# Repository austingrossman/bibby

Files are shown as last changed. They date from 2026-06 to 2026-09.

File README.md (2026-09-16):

# bibby — Brew In A Bag Temperature Ramp Controller

`bibby` is a temperature and power controller for electric brew-in-a-bag (BIAB)
brewing, running on a Raspberry Pi 5. It reads kettle temperature from a PT100
RTD, drives two mains heating elements through solid-state relays (SSRs), and
presents a touch UI for setting and tracking the brew temperature. Power is
delivered as a duty cycle synchronized to the AC mains zero crossing, and the
whole system is built so that any fault, crash, or hang leaves the heaters
**off**.

This README is meant to let someone unfamiliar with the project understand it,
reproduce the hardware, build the software, and calibrate it for their own
kettle. It moves from the big picture down to the details: architecture, then
hardware, then software, then build/bring-up, then calibration.

This project is for fun. I am doing it to improve my home brewing set up. I hope
that someone sees inspiration in this project and does something similar. I am
doing this with a couple specific goals in mind:
- Learn to use AI for coding purposes.
- I recently purchased a Mac mini. I will only use a Mac for this project and it
  forces me to learn how to use it.
- I've recently acquired a 3D printer. This project has one 3D printed part, so
  I should learn how to use it.

---

## Table of contents

1. [System overview](#1-system-overview)
2. [Software architecture](#2-software-architecture)
3. [Safety design](#3-safety-design)
4. [Hardware](#4-hardware)
5. [Raspberry Pi bring-up and installation](#5-raspberry-pi-bring-up-and-installation)
6. [Building bibby](#6-building-bibby)
7. [Configuration](#7-configuration)
8. [Running](#8-running)
   - [Web interface — screen mirror + log browser](#web-interface)
9. [Calibration methodology](#9-calibration-methodology)
10. [Data logging](#10-data-logging)
11. [Repository layout](#11-repository-layout)
12. [License](#12-license)

---

## 1. System overview

The controller is a **single process** with three threads sharing one in-memory
state block of C11 atomics (the optional web interface adds a few more, none of
them on the control path — §2.9):

```
  +----------------------------------------------------------------+
  |                    bibby (one process)                          |
  |                                                                |
  |  main/UI thread          sampler thread         SSR thread     |
  |  ---------------         ------------------     -------------  |
  |  LVGL touch UI on        60 Hz, DRDY-paced:     SCHED_FIFO,    |
  |  /dev/fb0 (rotated)      - MAX31865 read        ZC-paced:      |
  |  - kettle readout        - temp filter          - zero-cross   |
  |  - charts, slider        - PID (watts)            capture      |
  |  - fault band            - power split          - sigma-delta  |
  |          |               - CSV logging            SSR firing   |
  |          |               - batch-size estimator - watchdogs    |
  |          v                     |                     |         |
  |  +------------------ BibbyState (C11 atomics) -------+         |
  |            duties, temps, modes, faults, history               |
  +----------------------------------------------------------------+
        | SPI0 + DRDY (GPIO16)      | GPIO20 ZC     | GPIO21/26
        v                           |               v
  +-------------+            +-------------+   +-----------+
  |  MAX31865   |            | zero-cross  |   |   SSR1    |
  |  + PT100    |            | detector    |   |   SSR2    |
  +-------------+            +-------------+   +-----------+
        ^                          ^                |
        | RTD                      | AC mains       | switched mains
     kettle probe                  line sense       to heating elements
```

- The **SSR thread** owns the relays. It runs at real-time priority
  (`SCHED_FIFO`) so a GUI stall can never delay the zero-cross response or the
  watchdogs.
- The **sampler thread** owns the sensor and the control law. It publishes
  per-element duty commands into the shared state; it never touches the relays.
- The **UI thread** is a pure view/controller: it renders the state and writes
  user intent (setpoint, mode, manual watts). Nothing in it is on the control
  or safety path.
- Optionally, the **web interface** (§2.9) adds an accept thread, a
  framebuffer-capture thread and a short-lived thread per HTTP connection. They
  run at normal priority, hold no control state of their own, and reach the
  controller only by injecting pointer events into the UI — so everything above
  is unchanged whether it is running or not.

### Why a duty cycle synchronized to zero crossing?

The heating elements are resistive loads switched by zero-cross SSRs. Switching
only at the AC zero crossing eliminates the inrush/EMI of phase-angle control.
Power is modulated by choosing *which* mains half-cycles to pass — a duty cycle
in `[0, 1]`. A sigma-delta modulator (§2.3) spreads the fired cycles out evenly
so the average power tracks the command with minimal low-frequency flicker.

### Why watts, not duty?

The control law works in **watts**: the PID outputs a total power demand, and a
splitter turns watts into per-element duties using the configured element
ratings. This makes the tuned gains independent of which elements are fitted —
swap elements, update `bibby.ini`, and the loop still commands the same power
per degree of error. It also enables the equal-flux split and anti-scorch cap
(§2.4), which need to know real watts per cm².

---

## 2. Software architecture

### 2.1 Shared state — `src/state.{h,c}`

`BibbyState` is a single struct of C11 atomics shared by the three threads —
no locks on the hot paths. Key fields:

| Field | Writer | Purpose |
|---|---|---|
| `duty1`, `duty2` | sampler | per-element duty commands in `[0,1]` |
| `p_demand_w` | sampler | commanded power — also the delivered average power (§2.3) |
| `temp_raw_c`, `temp_filt_c`, `temp_valid` | sampler | latest sensor sample and validity |
| `setpoint_c`, `manual_mode`, `manual_power_w`, `grain_in` | UI | user intent |
| `simulate_zc` | main, at startup | bench zero-cross simulation (`mains.simulate_zc` / `--sim-zc`); never changes while running |
| `output1`, `output2`, `zc_count`, `watchdog_alarm` | SSR thread | fired state, ZC counter, ZC watchdog |
| `control_heartbeat` | sampler | bumped every loop pass; the SSR thread's staleness watchdog watches it |
| `rtd_fault`, `rtd_unresponsive`, `fault_forced_manual` | sampler | sensor-fault state |
| `m_est_l`, `adaptive_scale` | sampler | batch-size estimate (litres) and gain scale |
| `running` | main | global shutdown flag |

A mutex-guarded ring buffer of `HistPoint`s (one per 0.5 s) feeds the UI
charts; it is the only locked structure, and only the UI and the sampler's
0.5 s slow tick touch it.

### 2.2 Sampler thread — `src/sampler_thread.c`

Paced by the MAX31865 DRDY edge (one conversion per mains cycle, so ~60 Hz):

1. **Wait** for a DRDY falling edge (500 ms timeout so a dead sensor cannot
   stall the loop — the read also checks the DRDY level directly, so a missed
   edge still yields the conversion).
2. **Read** the sensor (§2.5); fresh samples go through the temperature filter
   (§2.6) and into the shared state.
3. **Mode interlock:** any RTD fault, unresponsive sensor, or invalid
   temperature forces **manual mode at zero watts** — automatic control can
   never command power on bad data.
4. **Control law** (§2.4): manual watts pass straight through; in auto, the
   watts-based PID runs once per fresh sample.
5. **Power split** (§2.4) turns the demand into `duty1`/`duty2`.
6. **Slow tick (0.5 s):** publish the batch-size estimate (§2.7) and push a
   chart history point.
7. **CSV logging** (§10): one row per fresh sample (or per 0.5 s during an
   outage, so faults stay on disk).

### 2.3 SSR thread — `src/ssr_thread.c`, `src/sigma_delta.h`

Runs at `SCHED_FIFO` (real-time) priority, pinned to the AC zero crossing:

1. **Zero-cross capture.** Wait for a rising edge on GPIO20 (libgpiod v2 edge
   events) with a mains-derived timeout: half-period + 0.7 ms guard — 9.0 ms at
   60 Hz, 10.7 ms at 50 Hz.
2. **Sigma-delta modulation.** Each zero crossing, add each element's duty
   fraction to a per-channel accumulator; fire that SSR for the half-cycle when
   the accumulator reaches 1.0 and subtract 1.0. The accumulator is capped at
   2.0 to bound catch-up after forced-off stretches. This is a first-order
   delta-sigma DAC clocked by the mains: the average fired fraction equals the
   commanded duty with the switching energy pushed to high frequency.
3. **Zero-cross watchdog.** No edge within the timeout → both SSRs forced off,
   `watchdog_alarm` set. A lost mains-sense signal must not leave a relay
   latched on. `simulate_zc` substitutes the timeout tick for the edge so the
   modulator can be exercised with no mains connected. It is set once at
   startup from `mains.simulate_zc` (or `--sim-zc`) and there is deliberately
   **no control for it on the panel**: while it is on this watchdog can never
   trip, which is a commissioning decision, not something a stray tap during a
   brew should be able to do. Startup logs a warning line whenever it is on.
4. **Control-staleness watchdog.** The sampler bumps `control_heartbeat` every
   pass; if it stops advancing for ~2 s worth of zero crossings
   (`2 × mains_Hz`), duties are forced to zero — a wedged control loop must not
   leave the heaters running. (`BIBBY_TEST_WEDGE=<sec>` wedges the sampler once,
   5 s in, to demonstrate exactly this on the bench.)

### 2.4 Control law — `src/control.c`, `src/power_split.c`

**PID (watts).** `p = kp·e`, integrator accumulates raw per-sample error
(`ki` is W/°C per sample), derivative is a raw per-sample delta. Output is
`clamp(ff + p + i + d, 0, max_power)` in watts. Anti-windup is **conditional
integration**: the integrator holds whenever the non-integral output is already
against a rail and the error would push further into it; a backstop clamps the
integral term to full output authority (`max_power / ki`).

**Integral clamp** (`pid.i_clamp_w`, watts; 0 = off). On top of that, the
integral *term* is bounded to ±`i_clamp_w` — the accumulator itself is held to
`i_clamp_w / ki`, every step, whether or not the integrator was allowed to
move. It is a statement of how much authority the integrator may ever have:
with the feedforward carrying the holding power, all the integrator has to
trim is model error, so it never needs kilowatts. The shipped value is 500 W,
about 5 % of the installed 10.5 kW — enough to absorb a wrong ambient or a
drifting `k_loss`, far too little to run away with the kettle. The tighter of
this and the `max_power / ki` backstop wins, and it applies to both gain sets.

**Integral separation** (`pid.i_band_c`, °C; 0 = off). The integrator only
accumulates while `|error| ≤ i_band_c`; outside the band it holds its value,
neither growing nor resetting. Anti-windup alone is not enough on this plant:
the kettle is an integrator, so a PI with an accurate feedforward must finish
a setpoint change with its integrator back near zero, which means every
degree-second of error it soaked up during the approach is paid back as
overshoot after the crossing. In the 2026-09-07 ramp test that accounted for
the whole 0.73 °C overshoot on a 10 °C step: the output was railed (and the
integrator held) only for the first 4 °C, then the integrator wound up for
250 s across the unsaturated approach and was still commanding 1.7 kW over
the holding power when the temperature first touched setpoint. With the
feedforward carrying the holding power the integrator has only model error to
trim, and there is nothing useful for it to learn while the temperature is
still degrees away, so the band confines it to the last half degree. The
band applies to both gain sets.

**Holding feedforward.** `ff = (setpoint − ambient_c) / process_gain_c` watts,
clamped to `[0, max_power]` — the steady-state power needed to hold the
setpoint, supplied directly so the integrator only trims model error (§9.6).
Zero gain disables it.

**Grain-in gain set.** The "Grain In" toggle swaps in an alternate gain set
(`grain.kp/ki/kd`) and optionally caps power (`grain.max_power_w`) — the plant
changes when grain is added, and scorch risk rises. Zero grain gains mean
"same as main gains disabled" (auto commands no power in grain mode until they
are set).

**Adaptive gain scaling** (config-gated, off by default). The batch-size
estimate in litres (§2.7) divided by `adaptive.m_ref_l` scales `kp`/`kd`
within `[scale_min, scale_max]` — a half-size batch gets half the gain without
retuning.

**Equal-flux power split.** Demand is split so both elements run at the same
surface power density (W/cm²): proportional to area, with saturation overflow
pushed to the other element and everything clamped to the element ratings.
With different elements (e.g. 5000 W/820 cm² + 5500 W/473 cm²) the duties are
deliberately unequal — same flux, different power. `power.max_flux_w_cm2`
optionally caps total demand at `flux × total_area` (anti-scorch; 0 disables).

### 2.5 MAX31865 RTD sensor — `src/max31865.c`

- PT100, **3-wire**, 400 Ω nominal reference resistor, on `/dev/spidev0.0` at
  1 MHz, `SPI_MODE_1`.
- **Init sequence:** set 3-wire + clear faults + mains filter notch → enable
  VBIAS (10 ms settle) → enable auto-conversion (20 ms) → discard the first 10
  conversions using DRDY polling (they settle after VBIAS/auto enable).
- **Mains filter:** config-register bit 0 selects the noise-rejection notch
  (set = 50 Hz, clear = 60 Hz). It is set from `mains.frequency_hz` (§7) in the
  first config word — before auto-conversion, as the datasheet requires.
- **`max31865_read()` is non-blocking:** it checks the DRDY level (GPIO16,
  active-low); not ready → previous value with `fresh=false`. Otherwise it
  burst-reads RTD + fault registers in one SPI transaction, converts via
  Callendar–Van Dusen, and applies the per-unit `Rref`/gain/offset calibration
  (§9.1–9.2).
- **Fault handling:** the RTD-LSB fault bit and Fault Status register are
  checked every read. A faulted conversion is rejected (the stale value is held
  so the filter is not poisoned) and the latch cleared so the status reflects
  the next conversion. `max31865_fault_text()` decodes the register for the UI
  fault band.

The MAX31865 datasheet is included at [`docs/MAX31865.pdf`](docs/MAX31865.pdf).

### 2.6 Temperature filter — `src/temp_filter.c`

Cascaded boxcar (moving-average) stages — order and window from `bibby.ini`
(default 2 × 40 samples ≈ a second-order CIC with triangular weighting, ~0.65 s
group delay at 60 Hz). The first sample primes every stage so the output starts
at the true temperature instead of ramping from zero.

### 2.7 Batch-size estimator — `src/mass_estimator.c`

During any stretch of roughly constant commanded power (taken as 0 W while the
ZC watchdog holds the SSRs off) where the temperature rises ≥ 1 °C, the kettle behaves as an integrator: `dT/dt = P/(m·c)`. A
least-squares slope over the stretch gives the thermal mass `P/slope` in J/°C,
which is reported as the equivalent litres of water, `m = (P/slope)/4186`, so
the number on the status line (`m 53.2 L`) and in the log (`m_est_l`) is a
batch size a brewer can sanity-check against what they poured in. It reads a
little high because the kettle, elements and hoses count as water, and it
reads `1/s` high when the elements put out a fraction `s` of their rated watts
(the shipped setup reads 53 L for 45 L poured; §9.4). It is always computed
and logged; feeding it back into the gains is the separate, config-gated
adaptive scaling of §2.4.

### 2.8 UI — `src/ui/`

LVGL 9.3 rendering directly to the framebuffer:

- **Display:** `lv_linux_fbdev` on `/dev/fb0`; the physical panel is portrait,
  mounted sideways, so the UI renders 1280×720 and LVGL software-rotates 90°
  into the 720×1280 framebuffer (`ui.rotation`). Touch comes from the first
  evdev device advertising absolute multitouch (`ui.touch_device = auto`).
- **Layout:** two large square toggles (Grain In, Manual Control) and the
  ±10/±1/±0.1 setpoint steppers on top; temperature chart (setpoint, filtered,
  raw, grain and mode-change markers) and power/PID-term chart below, each
  between a row of tappable legend chips above and a time scale below; a wide
  vertical power slider (manual watts in manual, live demand readout in auto);
  kettle graphic whose element glow follows the commanded duties and whose
  contents carry the batch-size estimate in litres and gallons, with the
  per-element duties and the adaptive gain scale under it; fault band (decoded
  RTD faults, watchdog, forced-manual notice).
- **Time scale:** both charts are right-aligned to *now* and span
  `ui.chart_window_min`, so the scale is fixed at startup and drawn once —
  six marks running `-5m … -1m … now` for the default 5-minute window, landing
  exactly on the chart's vertical grid lines (sub-minute marks read `-0:30`).
- **No dead space.** The two panes stretch from just under the toggles to the
  bottom edge. The fault band has no reserved strip: it is hidden nearly
  always, so it floats over the lower third of the power chart when it
  appears, which costs nothing — the loop is at zero watts by then.
- **Sized for fingers, not a mouse.** Every target is a touch target: the two
  toggles are 180×160, the steppers 120×75, the legend chips 46 px tall, and
  the power slider is 104 px wide — it is the only continuous control on the
  screen, so it gets a thumb's worth of track. The one thing the panel
  deliberately cannot do is arm zero-cross simulation (§2.3).
- LVGL is pinned to **v9.3.0**: v9.4 breaks the fbdev software-rotation path
  and hangs in `lv_deinit` on shutdown.
- **Memory (`src/ui/lv_conf.h`):** LVGL's built-in allocator is a fixed pool
  sized for microcontrollers — 64 KB by default, and this screen sits at ~36 KB
  of it with peaks near 42 KB, so a large redraw could exhaust the remainder and
  assert inside `lv_draw_add_task` ("Out of memory"). bibby therefore sets
  `LV_USE_STDLIB_MALLOC = LV_STDLIB_CLIB`: LVGL allocates from the system heap
  and there is no ceiling to tune.
- **Assertions:** LVGL's default `LV_ASSERT_HANDLER` is `while(1);`, which would
  wedge the UI thread at 100 % CPU — panel frozen, SIGTERM ignored, control
  threads still driving the elements. bibby sets it to `abort()` instead: the
  process dies, the kernel drops the GPIO requests, the SoC pull-downs hold the
  SSR inputs low, and `bibby.service` restarts it (§5.3).
- The kernel console shares `/dev/fb0` and will draw its blinking cursor over
  the UI; the systemd unit unbinds it (§5.3).

`bibby --ui-test` shows a bring-up screen instead: border, corner labels, and a
crosshair that follows the finger — verifies rotation and touch mapping before
trusting the real UI.

### 2.9 Web interface — `src/web/`

Optional, off by default, and configured entirely from `[web]` in `bibby.ini`
(§7). When enabled it adds an HTTP server on the LAN with two screens: a live
mirror of the touchscreen that can be tapped from a phone or laptop, and a
browser for the CSV run logs. Operator's guide in §8; safety in §3.

```
             browser                       bibby process
   ┌──────────────────────────┐   ┌────────────────────────────────────┐
   │  Screen tab              │   │  accept thread ─┬─ conn thread ─┐  │
   │   <img> long-poll   ─────┼───┼──> /api/screen.png              │  │
   │   pointer events    ─────┼───┼──> /api/input                   │  │
   │                          │   │                                 v  │
   │  Logs tab                │   │        capture thread     pointer  │
   │   file list, charts ─────┼───┼──> /api/logs /api/log     queue    │
   │   CSV download      ─────┼───┼──> /api/log/download        │      │
   └──────────────────────────┘   │             │               │      │
                                  │        mmap /dev/fb0        │      │
                                  │             │          UI thread   │
                                  │             └──────────> LVGL indev│
                                  └────────────────────────────────────┘
```

- **Screen mirror.** The capture thread `mmap`s `/dev/fb0` read-only and
  compares it against the previous frame; only a genuine pixel change bumps the
  frame sequence. It captures at most `web.screen_fps` times a second, and only
  while a browser is actually asking — an unwatched panel costs nothing.
  Requests **long-poll**: the server holds `/api/screen.png?seq=N` until the
  screen differs from the client's frame `N` (or 10 s pass, answering `204`), so
  a static screen uses no bandwidth and a touch appears within one frame.
  Frames are encoded as PNG (zlib, "Up" filter) — about 50 KB for a full
  1280×720 frame, and `?scale=2` halves each dimension for slow links.
- **Un-rotation.** The framebuffer is the *physical* portrait panel, sideways;
  the mirror applies `ui.rotation` so the browser shows what the operator at the
  kettle sees. The forward map is the same one LVGL uses on pointer input, so
  "display space" here is exactly LVGL's logical screen.
- **Pointer injection.** Taps post to `/api/input` in display coordinates. The
  server maps them back to panel coordinates and pushes them onto a small queue;
  a **second LVGL pointer indev**, created on the UI thread, drains that queue
  and reports the samples exactly as the evdev touchscreen does — so LVGL
  applies the same rotation to a remote tap as to a finger, and it lands on the
  pixel it looks like it lands on. LVGL is single-threaded and this queue is the
  entire boundary: no web thread ever makes an `lv_*` call. A press with no
  follow-up is auto-released after 2 s, so a browser that vanishes mid-drag
  cannot leave a widget held down.
- **Log browser.** `/api/logs` walks the CSV tree; `/api/log` streams one file
  through a bounded-memory decimator (rows accumulate into buckets; when the
  bucket array fills, adjacent buckets merge pairwise and the rows-per-bucket
  doubles) and returns a whole-file average of at most ~1400 points per series.
  A 75 MB, 459 k-row tuning log becomes 136 KB of JSON in about a second.
  `/api/log/download` serves the raw CSV, including the run in progress.
- **Path safety.** Every client-supplied path is `realpath()`d and required to
  resolve inside `~/bibby/logs` and to be a regular `.csv` file, so the server
  cannot be talked into serving anything else.
- **Authentication.** HTTP Basic against `web.user` / `web.password`, compared
  length-independently so a wrong password cannot be narrowed down by timing.
  The server **refuses to start with an empty password**. Failures are logged
  and answered after a 300 ms delay.
- **Cost.** Nothing at all when no browser is watching — the capture thread
  sleeps on a condition variable. With one browser on the Screen tab, measured
  on a Pi 5 at 1280×720 (percentages are of **one** core, of four; bibby idles
  at ~1.4 %):

  | | per frame | 2 fps | 5 fps |
  |---|---|---|---|
  | full resolution | ~19 ms, ~48 KB | ~5 % | ~11 % |
  | `scale=2` | ~8 ms, ~25 KB | ~3 % | ~6 % |

  The cost is linear in `web.screen_fps`, and the dominant term is the
  **un-rotate/pixel conversion (~8 ms), not the PNG compression (~11 ms
  including the filter)** — rotating means walking the framebuffer down a
  column, which defeats the cache. Two things keep it in hand: the conversion
  precomputes a per-pixel and per-row byte step instead of transforming each
  pixel's coordinates (worth ~10×), and the build is optimized (§6 — an
  unoptimized build costs ~67 ms per frame instead of 19). The web threads run
  at normal priority and are not on the control path; the SSR thread's
  `SCHED_FIFO` and the staleness watchdog are unaffected either way.
- The page is a single self-contained HTML file (`src/web/www/index.html`, no
  external assets or CDN) compiled into the binary at build time, so an
  installed `bibby` has no companion asset directory to lose.

---

## 3. Safety design

This system switches mains voltage into multi-kilowatt heating elements, so the
**default state is always off**. The design requirements and how they are met:

| Requirement | Mechanism |
|---|---|
| Heaters off at startup | SSR GPIO lines are requested with output value low before any thread runs |
| Heaters off on exit/crash | the kernel releases the GPIO lines when the process dies — for any reason — and the SoC pull-downs hold the SSR inputs low; SIGINT/SIGTERM additionally shut down in order |
| Only one instance | `flock` single-instance guard (`src/single_instance.h`); the kernel drops the lock on any exit |
| Heaters off if mains-sense (ZC) is lost | mains-derived zero-cross watchdog (~9 ms at 60 Hz) forces SSRs off, raises `watchdog_alarm`. The one thing that defeats it is bench mode (`mains.simulate_zc`, §2.3), which is why it lives in the config file and has no control on the panel |
| Heaters off if the control loop wedges | control-staleness watchdog: sampler heartbeat stalled for ~2 s of ZCs → duties forced to zero |
| GUI stalls cannot delay safety logic | the SSR thread runs `SCHED_FIFO`; the UI is not on the control path |
| No power commanded on unreliable temperature | RTD fault / unresponsive sensor forces manual mode at zero watts; auto is unreachable until the sensor is healthy |
| Power commands always bounded | demand clamped to the configured element ratings (and the optional flux cap) before splitting; duties clamped to `[0,1]` |
| The integrator cannot run away | conditional-integration anti-windup, plus a hard ± bound on the integral term (`pid.i_clamp_w`, 500 W as shipped) and the `max_power / ki` backstop (§2.4) |
| A vanished web client cannot hold a control down | an injected press with no follow-up sample is released after 2 s |
| Controller returns after a crash | `Restart=always` in the systemd unit (§5.3); SSRs are safe during the gap per the kernel-release mechanism above |
| Remote control cannot bypass an interlock | the web interface owns no control logic: it injects pointer events into the same LVGL widgets a finger drives (§2.9), so mode interlocks, clamps and watchdogs apply identically |
| Remote control is off unless deliberately enabled | `[web]` is disabled by default and the server refuses to start without a password; `web.allow_control = false` serves a read-only mirror |

---

## 4. Hardware

### 4.1 Major components

| Item | Notes |
|---|---|
| Raspberry Pi 5 | GPIO chip is `/dev/gpiochip4` on Pi 5 |
| Touchscreen display | 720×1280 DSI panel (Goodix touch), mounted sideways; UI software-rotates 90° |
| PT100 RTD probe | 3-wire, immersed in the kettle |
| 2 × zero-cross SSR | One per heating element; switched by GPIO21 / GPIO26 |
| 2 × resistive heating element | Mains-powered, BIAB kettle (this build: 5000 W and 5500 W) |
| Custom Pi HAT PCB | Sensor front-end + zero-cross detector (§4.2) |

> **TODO (fill in your build):** exact display model, SSR part numbers and
> current rating, fusing/contactor, and mains connector. These are
> deployment-specific and not captured in the repo.

### 4.2 Raspberry Pi HAT PCB — `pi_hat/bibby_pi_hat/`

A KiCad 7+ project (`.kicad_sch`, `.kicad_pcb`, `.kicad_pro`). Open it in KiCad
to view/edit the schematic and board, or to regenerate gerbers
(`pi_hat/bibby_pi_hat/gerbers/`). The HAT carries two functional blocks:

**RTD front-end (U1 — MAX31865):**
- `R1` = 400 Ω 0.1 % — RTD reference resistor (`Rref`). Precision and tempco here
  set the measurement accuracy; this is one of the two per-unit calibration
  anchors (§9.1).
- `C1`, `C3` = 0.1 µF — decoupling / RC filtering.
- SSOP-20 package; SPI to the Pi plus the DRDY data-ready line.

**AC zero-cross detector (U2 — H11AA1 AC-input optocoupler):**
- The H11AA1 has an anti-parallel LED input, so it conducts on both mains
  half-cycles and its phototransistor output pulses around each zero crossing.
- `R3`–`R6` = 43 kΩ, `R2` = 20 kΩ, `R7` = 1 MΩ (! DNI !) — line current-limiting
  and pull/bias network for the optocoupler. The pulse train feeds GPIO20.
- Solder jumpers `JP1`/`JP2`/`JP3` select options on the board.

**Connectors:**
- `J1` — 2×20 stacking header to the Pi GPIO.
- `J2` — Phoenix 1×10 5.08 mm terminal block (field wiring: RTD, mains sense,
  SSR drive).

> The complete, authoritative bill of materials and net list is the KiCad
> schematic itself. The values above are transcribed from it for orientation.

### 4.3 Pin assignments (40-pin header)

| Pin | GPIO | Signal | Direction | Used by |
|---|---|---|---|---|
| 1 | — | 3.3 V | Power | MAX31865 VIN |
| 6 | — | GND | Power | MAX31865 GND |
| 19 | GPIO10 | SPI0 MOSI | Out | MAX31865 SDI |
| 21 | GPIO9 | SPI0 MISO | In | MAX31865 SDO |
| 23 | GPIO11 | SPI0 SCLK | Out | MAX31865 CLK |
| 24 | GPIO8 | SPI0 CE0 | Out | MAX31865 CS |
| 36 | GPIO16 | DRDY | In | MAX31865 DRDY (sampler thread) |
| 37 | GPIO26 | SSR2 | Out | SSR thread |
| 38 | GPIO20 | Zero Cross | In | SSR thread |
| 40 | GPIO21 | SSR1 | Out | SSR thread |

### 4.4 Electrical / wiring overview

```
   MAINS L ---+----------------------------+--------------------+
              |                            |                    |
              |                       [SSR1 load]          [SSR2 load]
              |                            |                    |
        [ZC detector U2]             [Element 1]          [Element 2]
              |  (opto, isolated)          |                    |
              v                       [SSR1 line]          [SSR2 line]
        GPIO20 (ZC in)                     ^                    ^
                                           |                    |
   Pi 3.3V/GPIO control side:        GPIO21 (SSR1)        GPIO26 (SSR2)
                                      drive (3.3V logic into SSR input)

   PT100 RTD --3 wires--> MAX31865 (U1) --SPI0 + DRDY--> Pi
```

- The H11AA1 provides **galvanic isolation** between the mains line-sense and
  the Pi logic.
- The SSRs are driven by 3.3 V GPIO on their input side; their output side
  switches mains into the elements.
- The RTD is a low-voltage measurement isolated from the mains by the kettle
  and the sensor front-end.

> **WARNING:** mains wiring, fusing, grounding/earth bonding, and enclosure
> safety are the integrator's responsibility. Use appropriately rated SSRs and
> heat-sinking, a proper earth connection to the kettle, and a
> contactor/fuse/breaker sized to the elements.

### 4.5 Enclosure

> **TODO (fill in your build):** enclosure material and dimensions, panel cutout
> for the display, ventilation/heat-sinking for the SSRs, and how the Pi + HAT +
> SSRs are mounted. Add photos and mechanical drawings here.

---

## 5. Raspberry Pi bring-up and installation

Tested target: **Raspberry Pi 5**, 64-bit Raspberry Pi OS.

### 5.1 OS and interfaces

1. Flash Raspberry Pi OS (64-bit) and boot the Pi. Install a beefy SD card (or
   other storage) for logging. Find a way to remote-login to the Pi.
2. Enable SPI:
   ```
   sudo raspi-config   # Interface Options -> SPI -> Enable
   ```
   Confirm `/dev/spidev0.0` exists after reboot.
3. The DSI touch display is auto-detected (`display_auto_detect=1` in
   `/boot/firmware/config.txt`). The touch controller registers as a Goodix
   evdev device; bibby finds it automatically.
4. The Pi 5 exposes GPIO via `/dev/gpiochip4`; the code opens it directly. The
   user running bibby needs the `gpio`, `spi`, `video`, and `input` groups (or
   run via the systemd unit, §5.3).

### 5.2 Build dependencies

```
sudo apt update
sudo apt install -y build-essential cmake git libgpiod-dev zlib1g-dev
```

- **libgpiod v2** is required (the code uses the v2 edge-event API). Confirm
  with `gpiodetect` / `pkg-config --modversion libgpiod`.
- **LVGL** is fetched and built from source by CMake (FetchContent) — nothing
  to install. It renders straight to the framebuffer; no X, Wayland, or GL
  stack is needed.
- The analysis tools (§9.4) additionally want
  `pip3 install numpy scipy matplotlib pandas` on whatever machine runs them.

### 5.3 Autostart at boot (systemd)

[`deploy/bibby.service`](deploy/bibby.service) is the reference unit. Besides
starting bibby it handles three things the app cannot do for itself:

- **Unbinds the kernel console from the framebuffer** (`vtcon1`) before start —
  otherwise the console's blinking cursor (and any kernel message) draws over
  the UI — and rebinds it on stop.
- **`LimitMEMLOCK=64M`** so `mlockall(MCL_CURRENT)` succeeds (the default 8 MB
  is too small once LVGL is linked in).
- **`AmbientCapabilities=CAP_SYS_NICE`** so the SSR thread gets its `SCHED_FIFO`
  real-time priority without running the whole process as root.

Install:

```
sudo cp deploy/bibby.service /etc/systemd/system/
sudo systemctl daemon-reload
sudo systemctl enable --now bibby
```

Check status and logs with `systemctl status bibby` / `journalctl -u bibby -f`.
Adjust `User=` and the paths in the unit for your username/checkout. The unit
uses `Restart=always`: the controller comes back if it ever dies, and the SSRs
are safe during the gap (§3).

---

## 6. Building bibby

```
git clone <repo-url> bibby
cd bibby
cmake -S . -B build -DCMAKE_BUILD_TYPE=Release
cmake --build build -j
```

If you omit `CMAKE_BUILD_TYPE`, CMake would normally configure with **no `-O`
flag at all**; `CMakeLists.txt` therefore defaults it to `RelWithDebInfo`
(`-O2 -g`) when it is unset. This matters more than it sounds: an unoptimized
build runs LVGL's renderer and the web mirror's pixel conversion roughly four
times slower (§2.9). Check an existing build tree with

```
grep C_FLAGS build/CMakeFiles/bibby.dir/flags.make
```

and re-run `cmake -S . -B build -DCMAKE_BUILD_TYPE=RelWithDebInfo` if it shows
no `-O2` — a build directory keeps whatever type it was first configured with.

The first configure fetches LVGL (pinned to v9.3.0 — see §2.8) from GitHub.
Two binaries result:

- `build/bibby` — the controller (links `lvgl`, `gpiod`, `z`, `m`, `pthread`,
  `rt`; `z` is only used by the web screen mirror, §2.9)
- `build/tests` — unit tests for the pure modules (no hardware needed):

```
./build/tests
```

`build/` and `logs/` are gitignored. There is no install step yet; run from the
build tree (the systemd unit does the same). The config file is found relative
to the executable (§7), so a copied-out binary works if `bibby.ini` sits next
to it.

---

## 7. Configuration

Runtime parameters that depend on the install (mains region, heating elements,
control gains, calibration) live in **`bibby.ini`**, **not** in the source.
There is no reason to edit a constant in code and rebuild to adapt a new brew
setup.

**Lookup order:** `-c <path>` argument → `$BIBBY_CONFIG` environment variable →
`bibby.ini` next to the executable → `bibby.ini` in the current directory.
A missing file or unknown key falls back to a built-in safe default (60 Hz,
zero gains), so the system still comes up. Comments (`#` or `;`, inline
allowed) and blank lines are ignored.

All keys, with their defaults:

| Key | Default | Effect |
|---|---|---|
| `mains.frequency_hz` | 60 | ZC watchdog timeout (half-period + 0.7 ms), staleness cutoff (2×Hz ZCs ≈ 2 s), MAX31865 notch (50/60 Hz) |
| `mains.simulate_zc` | false | **bench only:** treat ZC-watchdog timeouts as zero crossings, so the whole loop runs with no AC connected (§2.3). The mains-loss watchdog cannot trip while it is on, so it is a config switch with no panel control; `--sim-zc` forces it on for one run |
| `element1.watts` / `element2.watts` | 2500 / 2500 | element ratings; their sum is the maximum power demand |
| `element1.area_cm2` / `element2.area_cm2` | 150 / 150 | wetted areas driving the equal-flux split |
| `power.max_flux_w_cm2` | 0 (off) | anti-scorch cap: total demand ≤ flux × total area |
| `pid.kp` / `ki` / `kd` | 0 | watts-based gains (§9.5); zero = auto commands no power |
| `pid.i_band_c` | 0 (off) | integral-separation band, °C: the integrator only accumulates within it (§2.4); both gain sets |
| `pid.i_clamp_w` | 0 (off) | ± bound on the integral term, watts (§2.4); the tighter of this and the `max_power / ki` backstop applies; both gain sets |
| `grain.kp` / `ki` / `kd` | 0 | alternate gain set while "Grain In" is on |
| `grain.max_power_w` | 0 (off) | power cap while grain is in |
| `feedforward.process_gain_c` | 0 (off) | identified K [°C/W]; holding feedforward `(setpoint−ambient)/K` watts |
| `feedforward.ambient_c` | 20 | feedforward reference temperature |
| `sensor.ref_resistor_ohms` | 400 | MAX31865 Rref, ice-point trimmed (§9.1) |
| `sensor.temp_cal_gain` / `temp_cal_offset` | 1.0 / 0.0 | two-point span trim, `T_true = g·T + b` (§9.2) |
| `filter.order` / `filter.window` | 2 / 40 | boxcar cascade stages and window length (§2.6) |
| `logging.rate` | high | `high` = row per sample (60 Hz); `low` = row per `low_period_s` |
| `logging.low_period_s` | 2.0 | row period in low-rate mode |
| `ui.chart_window_min` | 5 | chart time window, minutes (1–30) |
| `ui.rotation` | 90 | UI rotation onto the panel: 0/90/180/270 |
| `ui.fb_device` / `ui.touch_device` | auto | `auto` = `/dev/fb0` / first multitouch evdev; or explicit paths |
| `web.enable` | false | start the web interface (§8); ignored unless `web.password` is set |
| `web.port` | 8080 | TCP port |
| `web.bind` | 0.0.0.0 | `0.0.0.0` = whole LAN; `127.0.0.1` = the Pi only (ssh tunnel) |
| `web.user` / `web.password` | brewer / *(empty)* | HTTP Basic credentials; **empty password = server refuses to start**. No `#` or `;` (INI comment characters) |
| `web.allow_control` | true | `false` serves a read-only mirror — the screen updates, taps are rejected |
| `web.screen_fps` | 5 | cap on mirror capture rate, 1–30 (only captures while a browser is watching) |
| `adaptive.enable` | false | scale kp/kd by (batch-size estimate / `m_ref_l`) |
| `adaptive.m_ref_l` | 0 | batch size the gains were tuned at, litres, as the estimator reads it (§9.5) |
| `adaptive.scale_min` / `scale_max` | 0.5 / 4.0 | clamp on the adaptive scale |

The shipped `bibby.ini` documents each value's derivation inline; §9 gives the
full procedures.

---

## 8. Running

```
./build/bibby                  # the normal touch UI
./build/bibby --ui-test        # display/touch bring-up screen (§2.8)
./build/bibby --headless       # no display: prints a status line every 2 s
./build/bibby --sim-zc         # start with simulated zero crossings (bench)
./build/bibby --manual-w 8000  # start in manual at 8000 W (plant-ID tests)
./build/bibby -c /path/to.ini  # explicit config
```

If the framebuffer cannot be opened the UI falls back to headless mode rather
than exiting — the controller and safety logic keep running.

### UI elements

- **Kettle card:** setpoint in °C and °F above it, the measured temperature in
  °C and °F at the same size inside it (°F a shade darker, so °C still reads
  first), the batch-size estimate on the contents in **litres and US gallons**,
  animated elements whose glow tracks the commanded duty, and a per-element
  duty readout below (`E1 x%  E2 y%` — these differ by design; see the
  equal-flux split, §2.4).
- **POWER slider:** commands watts in manual mode; shows the loop's live demand
  in auto (disabled for input). Total watts read out under it. It is 104 px
  wide — deliberately, for a wet thumb.
- **Setpoint steppers:** ±10 / ±1 / ±0.1 °C.
- **Toggles:** two square pads — Grain In (gain set swap + logged event marker)
  and Manual Control (manual watts vs PID auto). Zero-cross simulation is not
  among them; it is `mains.simulate_zc` in the config (§2.3, §7).
- **Charts:** temperature (setpoint / temp / raw + grain-event and mode-event
  markers — short dashes along the top edge at the samples where Grain In or
  Manual flipped) and power (demand W / ff / P / I / D), window set
  by `ui.chart_window_min`, y-autoscaled. Each carries a time scale under it
  reading backwards from `now` to the full window.
- **Chart legends:** each trace has a chip under its chart — tap to drop that
  trace. A hidden trace is neither drawn nor counted in that chart's autoscale,
  so switching off the terms you are not tuning zooms the pane onto the rest.
  Chips are colored when on, greyed and struck through when off; all traces
  start visible on every launch.
- **Fault band:** decoded RTD faults, watchdog alarm, and "Auto disabled →
  manual" when a fault forced the mode switch.
- **Status line:** the adaptive gain scale, under the per-element duties at the
  foot of the kettle column. (The batch-size estimate that drives it is on the
  kettle contents.)

### Web interface

Off by default. To turn it on, set a password in `[web]` (§7) and restart:

```ini
[web]
enable        = true
port          = 8080
bind          = 0.0.0.0        ; 127.0.0.1 to reach it only through an ssh tunnel
user          = brewer
password      = pick-something-long
allow_control = true           ; false for a read-only mirror
screen_fps    = 5              ; halve it if you want the CPU back; 2 is still responsive
```

Then browse to `http://<pi-address>:8080/` and enter the user and password.
Startup logs the URL it is serving and whether control is enabled:

```
web: mirroring /dev/fb0, panel 720x1280 32 bpp, rotation 90 -> 1280x720
web: http://0.0.0.0:8080/ as user "brewer" (remote control ENABLED)
web: remote pointer attached
```

**Screen tab** — a live mirror of the panel, upright the way you see it at the
kettle. It is the real framebuffer, not a re-drawing, so it shows exactly what
the touchscreen shows. Click or drag anywhere on it and the tap is injected
into the UI as a pointer event: setpoint steppers, the power slider, and the
toggles all behave as they do under a finger. Quality can be dropped to half
resolution for a weak connection. The mirror pauses while the Logs tab is open
or the browser tab is hidden.

**Logs tab** — every run under `~/bibby/logs` newest first (the run in progress
is marked "● live"). Pick one to plot it: temperature (filtered / raw /
setpoint) and power (demand, ff/P/I/D, and per-element duty on a
right-hand axis). Legend chips toggle traces, and hovering reads out every
visible series at that instant. **Download CSV** fetches the raw file — the
same one `tools/identify_plant.py` and `tools/plot_logs.py` expect — so a brew
can be pulled off the Pi from a laptop without ssh. Long logs are averaged
server-side to about 1400 points for plotting; the download is always the full,
unmodified file.

**Before you enable it, read this.** The mirror puts the kettle controls on
your network. Everything the panel can do, a browser with the password can do,
including raising the setpoint or commanding power on a multi-kilowatt element.
Every interlock still applies — remote taps go through the same widgets, so a
sensor fault still forces manual at 0 W, and the watchdogs are untouched — but
the *authorization* is only that password, over plain HTTP:

- Use it on a trusted home network, with a password you use nowhere else.
- **Do not forward the port through your router.** There is no TLS; anyone who
  can watch the traffic can read the password. For access from outside the
  house, set `bind = 127.0.0.1` and reach it through an ssh tunnel:
  `ssh -L 8080:localhost:8080 ramp` , then browse to `localhost:8080`.
- Set `allow_control = false` when you only want to watch a brew — the screen
  still updates live, but taps are rejected by the server.
- Leave `enable = false` if you do not want any of this; there is no default
  password and the server will not start without one.

**Bench testing without mains:** set `simulate_zc = true` in `[mains]`, or
start with `--sim-zc` to avoid editing the file. The SSR thread then clocks the
sigma-delta from its timeout tick instead of the missing zero-cross edge; the
full UI, control law, and logging run with no AC connected. Startup prints

```
bibby: ZERO-CROSS SIMULATION ON (--sim-zc) - the mains-loss watchdog cannot trip; bench use only
```

**Turn it off before the controller is wired to a kettle.** With it on, losing
the mains-sense signal looks exactly like normal operation to the SSR thread,
so the ZC watchdog — one of the interlocks in §3 — is inert. There
is no toggle for it on the panel for that reason: it should change when the
unit is on a bench, not when someone is brewing on it.

---

## 9. Calibration methodology

Three of the measurement constants are **per-unit** — they depend on the
specific RTD probe and the board's reference resistor, so they **must be
re-derived for any other board or probe**. All three live in the `[sensor]`
section of `bibby.ini`; **none require a code change or rebuild**. Their
identity defaults (`Rref` = 400 Ω, gain = 1.0, offset = 0.0) give a working but
uncalibrated sensor.

`tools/calibrate_sensor.py` does the §9.1/§9.2 arithmetic for you (standard
library only):

```
python3 tools/calibrate_sensor.py rref --ice-reading 1.4 --rref-current 400
python3 tools/calibrate_sensor.py span --p1 0.0 0.0 --p2 25.0 23.78
```

| `bibby.ini` key | Symbol | What it corrects |
|---|---|---|
| `sensor.ref_resistor_ohms` | `Rref` | one-point offset at the ice point (§9.1) |
| `sensor.temp_cal_gain` | `g` | span/slope error across temperature (§9.2) |
| `sensor.temp_cal_offset` | `b` | residual offset after the span fit (§9.2) |

The driver applies them in this order, so **calibrate in this order too**:

```
R_rtd  = (raw / 32768) * Rref            # ref_resistor_ohms  (§9.1)
T_cvd  = CVD(R_rtd)                      # Callendar–Van Dusen, fixed
T_true = g * T_cvd + b                   # gain, offset       (§9.2)
```

### 9.1 Reference resistor `Rref` (ice-point one-point trim)

`Rref` scales the entire resistance reading, so trimming it nulls a constant
offset. Trim it first, at a single known low temperature (the ice point is the
cheapest 0 °C reference available).

**Procedure**

1. Set `sensor.temp_cal_gain = 1.0`, `sensor.temp_cal_offset = 0.0` (so the
   span trim does not mask the reading), and `sensor.ref_resistor_ohms` to the
   board's nominal reference (400 Ω here — the value of `R1` on the HAT, §4.2).
2. Submerge the probe in a well-stirred ice-water bath and let it settle.
3. Read the measured temperature `T_ice` (the **raw** column in the CSV log,
   §10, before any span trim).
4. The PT100 resistance the probe *should* present at `T_ice` is, from
   Callendar–Van Dusen with `R0 = 100 Ω`, `A = 3.9083e-3`:
   `R_pt100(T) = 100·(1 + A·T + B·T²)`, which near 0 °C is ≈ `100·(1 + A·T)`.
   Because the reading scales linearly with `Rref`, the trimmed value is:

   ```
   Rref = Rref_nominal · 100.0 / R_pt100(T_ice)
   ```

**Worked example (this unit):** read **+1.4 °C** in the ice bath.
`R_pt100(1.4) = 100·(1 + 3.9083e-3·1.4) ≈ 100.547 Ω`, so
`Rref = 400 · 100.0 / 100.547 = 397.82 Ω` → `sensor.ref_resistor_ohms = 397.82`.

### 9.2 Span trim `gain`/`offset` (two-point line fit)

With `Rref` set, a probe can still read low or high **in proportion to
temperature** (a probe α / self-heating mismatch). That is a slope error, so it
is corrected in the temperature domain by a straight line through **two**
reference points `(T1_ref, T1_meas)` and `(T2_ref, T2_meas)`, where `T_meas` is
the reading **after** the §9.1 trim:

```
gain   = (T2_ref - T1_ref) / (T2_meas - T1_meas)
offset =  T1_ref - gain · T1_meas
```

Pick the two points as far apart as practical and bracketing the brew range for
the best fit. Good choices: the ice point (0 °C) and the local **boiling
point** (altitude-corrected, below). A stirred ambient bath against a trusted
reference thermometer also works for the upper point.

**Boiling-point reference.** Water boils below 100 °C at altitude; approximate
the local boiling point as `T_boil ≈ 100 − 3.4·(h/1000m)` (°C, `h` =
elevation), or read it from a steam table for your barometric pressure, then
use that as the upper `T_ref`.

**Worked example (this unit):** ice point `(0.00, 0.00)` and a fan-mixed
ambient point `(25.00, 23.78)`:
`gain = (25.00 − 0.00)/(23.78 − 0.00) = 1.0513`,
`offset = 0.00 − 1.0513·0.00 = 0.0`. After a small refinement the shipped
values are `sensor.temp_cal_gain = 1.0528`, `sensor.temp_cal_offset = -0.032`.

> **PROVISIONAL:** both points above are ≤ 25 °C. Re-fit using a boiling-point
> upper reference before trusting brew-range temperatures — at 5230 ft the
> local boiling point is **94.7 °C**, and the §9.1-trimmed RTD should read
> ~90.0 °C there. Re-derive both keys for your own probe and altitude.

### 9.3 Process model

The model of the signal chain from power command to measured temperature has
three cascaded stages: the kettle thermal plant, the RTD probe lag, and the
software filter.

#### Signal chain

```
  P [W] ──►[ G_plant ]──► T_kettle ──►[ G_probe ]──►[ G_filt ]──► T_meas ──► PID
            K/(τs+1)                  1/(τ_pr s+1)   boxcar cascade

  plant heat loss: T_kettle relaxes toward ambient at rate k_loss·(T − T_amb)
```

#### Kettle thermal plant

Energy balance of a well-stirred (recirculated) kettle, linearised about an
operating point: the stored energy rises with the electrical power poured in
and falls with the heat leaking to the room.

$$m\,c_p\,\frac{dT}{dt} \;=\; P \;-\; k_{\text{loss}}\,\bigl(T - T_{\text{amb}}\bigr)$$

| Symbol | Meaning | Units |
|---|---|---|
| $T$ | kettle liquid temperature — the controlled variable | °C |
| $T_{\text{amb}}$ | ambient temperature the kettle relaxes toward unpowered | °C |
| $P$ | total electrical power delivered by the elements — the manipulated variable | W |
| $m$ | liquid mass | kg |
| $c_p$ | specific heat, 4186 for water | J/(kg·°C) |
| $k_{\text{loss}}$ | total heat-loss coefficient (conduction through walls and lid, radiation, evaporation) | W/°C |

Work in deviation variables so the constant ambient term drops out. Let
$\theta \equiv T - T_{\text{amb}}$; with $T_{\text{amb}}$ constant
$\dot\theta = \dot T$, so

$$m\,c_p\,\dot\theta + k_{\text{loss}}\,\theta \;=\; P$$

Laplace transform, starting from the operating point so $\theta(0) = 0$:

$$m\,c_p\,s\,\Theta(s) + k_{\text{loss}}\,\Theta(s) \;=\; P(s)
\quad\Longrightarrow\quad
\bigl(m\,c_p\,s + k_{\text{loss}}\bigr)\,\Theta(s) \;=\; P(s)$$

Solve for the transfer function and divide numerator and denominator by
$k_{\text{loss}}$ to reach standard first-order form:

$$G_{\text{plant}}(s) \;=\; \frac{\Theta(s)}{P(s)}
\;=\; \frac{1}{m\,c_p\,s + k_{\text{loss}}}
\;=\; \frac{1/k_{\text{loss}}}{\dfrac{m\,c_p}{k_{\text{loss}}}\,s + 1}
\;=\; \frac{K}{\tau s + 1}$$

$$K = \frac{1}{k_{\text{loss}}}\ \left[\text{°C/W}\right]
\qquad
\tau = \frac{m\,c_p}{k_{\text{loss}}}\ \left[\text{s}\right]$$

where $K$ is the steady-state gain (°C of rise per watt held) and $\tau$ the
dominant time constant.

For a 30 L batch in a reasonably insulated kettle $\tau$ is typically **20–40
minutes**. The initial ramp rate at power $P$ is $P/(m\,c_p)$ — easy to check
directly against the heating phase of the identification test, and the basis of the online $m\,c$ estimator
(§2.7).

#### RTD probe lag

The PT100 element sits inside a sheath with its own thermal mass, so it reports
a lagged version of the liquid temperature. Treating the sheath as a lumped
mass exchanging heat with the liquid through a film conductance gives the same
first-order form as the kettle:

$$m_{\text{pr}}\,c_{\text{pr}}\,\frac{dT_{\text{pr}}}{dt}
\;=\; h A\,\bigl(T - T_{\text{pr}}\bigr)
\quad\Longrightarrow\quad
\tau_{\text{probe}}\,\dot T_{\text{pr}} + T_{\text{pr}} \;=\; T$$

$$G_{\text{probe}}(s) \;=\; \frac{T_{\text{pr}}(s)}{T(s)}
\;=\; \frac{1}{\tau_{\text{probe}}\,s + 1},
\qquad \tau_{\text{probe}} = \frac{m_{\text{pr}}\,c_{\text{pr}}}{hA}
\;\approx\; 5\text{–}30\ \text{s}$$

| Symbol | Meaning | Units |
|---|---|---|
| $T_{\text{pr}}$ | temperature the probe actually reports | °C |
| $T$ | true liquid temperature (the plant output above) | °C |
| $m_{\text{pr}} c_{\text{pr}}$ | thermal mass of the sheath and element | J/°C |
| $hA$ | film conductance from liquid to sheath | W/°C |
| $\tau_{\text{probe}}$ | probe time constant — thin bare sheath at the low end, thick thermowell at the high end | s |

Its DC gain is 1: the probe eventually reaches the liquid temperature, it just
gets there late. That is why $\tau_{\text{probe}}$ shows up as dead time in the
FOPDT fit rather than as a gain error.

#### Software filter

The default filter is $n = 2$ cascaded boxcars of $N = 40$ samples each, run at
the sensor rate $f_s \approx 60\ \text{Hz}$ (one conversion per mains cycle).
A single $N$-sample boxcar is

$$G_{\text{box}}(z) \;=\; \frac{1}{N}\sum_{k=0}^{N-1} z^{-k},
\qquad
G_{\text{filt}}(z) \;=\; \bigl[G_{\text{box}}(z)\bigr]^{\,n}$$

Its taps are uniform, so the group delay is the mean tap index — $(N-1)/2$
samples — and $n$ identical stages in series simply add:

$$L_{\text{filt}}
\;=\; \frac{n\,(N-1)}{2\,f_s}
\;=\; \frac{2 \cdot 39}{2 \cdot 60}
\;\approx\; 0.65\ \text{s}$$

with each stage contributing $(N-1)/(2 f_s) \approx 0.33\ \text{s}$. Both $n$
and $N$ are `filter.order` / `filter.window` in the INI; changing them changes
the dead time below, so re-identify the plant afterward.

#### Combined FOPDT approximation

Cascading the three stages gives a third-order model. The two small lags —
probe and filter — are far faster than the kettle, so the standard reduction
(Skogestad half-rule, in the limit where the small time constants are much
smaller than the dominant one) folds them into a pure delay:

$$G(s) \;=\; \underbrace{\frac{K}{\tau s + 1}}_{\text{kettle}}
\cdot \underbrace{\frac{1}{\tau_{\text{probe}} s + 1}}_{\text{probe}}
\cdot \underbrace{G_{\text{filt}}(s)}_{\text{filter}}
\;\;\approx\;\; \frac{K\,e^{-Ls}}{\tau s + 1}$$

using $\dfrac{1}{\tau_{\text{probe}} s + 1} \approx e^{-\tau_{\text{probe}} s}$
for $\tau_{\text{probe}} \ll \tau$, so the delays add:

$$K \approx \frac{1}{k_{\text{loss}}}\ \left[\text{°C/W}\right]
\qquad
\tau \approx \frac{m\,c_p}{k_{\text{loss}}}\ \left[\text{s}\right]
\qquad
L \approx \tau_{\text{probe}} + L_{\text{filt}}\ \left[\text{s}\right]$$

The ratio $L/\tau$ characterises controllability: $L/\tau < 0.3$ is
straightforward; $L/\tau > 1.0$ is delay-dominated. A BIAB kettle sits well
below 0.3 — with $L \approx 10\text{–}30\ \text{s}$ against a $\tau$ of tens of
minutes, the challenge is the large time constant, not the dead time.

#### Gain conventions — continuous vs. INI

The PID accumulates raw error once per sample (`integral += e`, not `e·dt`)
and uses raw per-sample deltas for the derivative. The INI gains relate to
continuous-time gains by:

```
kp_ini = Kp_c            [W/°C, unchanged]
ki_ini = Ki_c · T_s      [T_s = sample period ≈ 1/60 s]
kd_ini = Kd_c / T_s
```

`identify_plant.py` measures `T_s` from the log and folds it in automatically.

### 9.4 System identification

`m` (the batch size, litres), `k_loss`, and `L` come from a **heat-then-cool test**: run the elements
at a fixed high power in manual mode until the kettle reaches mash
temperature, then turn them off and let it cool. `tools/identify_plant.py`
drives the lumped model of §9.3 with the logged power demand `p_demand_w`
(which the modulator delivers, §2.3; rows where the ZC watchdog was up count
as 0 W), fits the three parameters to the measured temperature by least
squares, and prints ready-to-paste `[pid]`/`[feedforward]` blocks.

Each phase pins down something the other cannot:

| Phase | Determines | Why |
|---|---|---|
| Heating ramp | `m` | slope = P / (m·c); the loss term is small against 8 kW |
| Power on/off corners | `L` | the measured trace turns `L` seconds after the power does |
| Cooling decay | `k_loss` | at 0 W the kettle relaxes toward ambient at rate k_loss / m·c |

A constant-power step alone cannot separate `K` from `τ` unless it runs to
steady state, which for a BIAB kettle at any useful power sits above boiling.
The cooling phase removes that problem: `K = 1/k_loss` and `τ = m·c/k_loss`
follow directly.

#### Test procedure

1. **Fill** the kettle to the intended brew volume, with the lid and the
   recirculation pump exactly as you will brew. `k_loss` depends on the lid,
   insulation, and pump heat, so the test setup must match the brew setup.
   Good mixing is required for the lumped model to hold.
2. **Measure the room temperature** with a separate thermometer near the
   kettle. This is the `--ambient` input; the script does not estimate it.
3. **Start bibby** (the CSV logger runs from startup) and leave it a minute at
   0 W so the log has a quiet lead-in.
4. **Heat.** Manual Control on; set the power slider to about **80 %** of
   maximum and leave it until the temperature reaches mash temperature
   (**~65 °C**). Do not approach boiling: evaporation changes `k_loss`.
   (`--manual-w` on the command line applies the power from startup.)
5. **Cool.** Slider to 0 W. Leave the pump running and the lid as it was, and
   let the kettle cool until the temperature has dropped **at least 5 °C**;
   30 minutes or more is better. The longer the decay, the tighter `k_loss`.
   A well-insulated kettle cools very slowly (a cooling time constant of
   hours is normal), so give it an hour or more — the holding power near mash
   temperature is pinned down early, but separating `k_loss` from the ambient
   value takes a longer decay.
6. **Stop** bibby and copy the log from `~/bibby/logs/YYYY/MM/DD/HH-MM-SS.csv`.

The power trace does not have to be clean — the script uses whatever
`p_demand_w` was, sample by sample — but the plant must not
change mid-test (no adding water, no lid on/off).

#### Running the identification

```
pip3 install numpy scipy matplotlib pandas    # once

python3 tools/identify_plant.py logs/YYYY/MM/DD/HH-MM-SS.csv \
        --ambient 21.5 --volume-l 45 -o plant_fit.png

# τc (--lambda) sets how aggressive the SIMC gains are (§9.5); the shipped
# bibby.ini uses 30 s, the script's default is max(3L, 120 s):
python3 tools/identify_plant.py logs/... --ambient 21.5 --lambda 30
```

The whole log is used; there is no window to choose. `--ambient` is the room
temperature you measured, in °C; `--volume-l` is the water you put in, used
only for the element-watts cross-check below. The script prints:

- the power phases it found (heat/cool spans, mean watts, temperature range);
- the fitted `m` in litres (compare against what you poured in), `k_loss`, and `L`,
  each with a standard error, the fit RMSE overall and per phase, and a
  cross-check fit with the ambient left free — a gap of more than a couple of
  °C from your `--ambient` means the room reading or the setup is off;
- warnings when the log cannot support the fit: no cooling phase, a poorly
  determined `k_loss`, temperatures above 90 °C, or a large RMSE;
- two corner diagnostics the lumped model does not contain (below): the dead
  time read directly off the power-on corner, and the mixing offset;
- with `--volume-l`, the ratio of the fitted `m` to the litres you put in.
  A ratio well above 1 means the elements put out fewer watts than
  `element1_watts`/`element2_watts` claim — mains below the rating voltage,
  element resistance tolerance, SSR drop. The gains and feedforward are still
  correct: the controller, the log, and the fit all work in the same nominal
  watts, so the factor cancels in the loop. Only the displayed watts, the
  on-screen `m`, and the flux cap are mislabeled. If you correct the INI
  ratings by a factor `s` (measure V and R, `P = V²/R`), scale `kp` and `ki`
  by `s` and `process_gain_c` by `1/s`, or rerun the test — changing the
  ratings alone makes the loop `1/s` more aggressive;
- the FOPDT equivalents `K`, `τ`, `L`, tuned gains per rule, and the INI blocks.

**Corners.** A real kettle does two things at the power transitions that a
lumped mass cannot. First, the probe usually sits in the recirculation flow
downstream of the elements and reads a few tenths of a degree above the bulk
while they run — visible as a fast drop in the first minute after power-off.
The script reports this *mixing offset*; scaled to holding power it is
hundredths of a degree and can be ignored for control. Second, because that
transient dominates the corners, the least-squares dead time is unreliable
(it went to zero on the first real run). The script therefore also reads `L`
straight off the power-on corner — the time for the measured slope to reach
half its steady ramp value — and uses the larger of the two for tuning.

The plot shows the measured temperature against the model (heating phases
shaded), the commanded power, and the residuals. Spikes in the residual at the
power corners are the mixing offset and probe lag above. A residual that
drifts through the cooling phase means `k_loss` or the ambient value is wrong.

| Parameter | Physical meaning | Implication |
|---|---|---|
| `m` | Batch size, litres of water (thermal mass m·c = 4186·m J/°C) | Sanity check vs. what you poured; sets the ramp rate P/(m·c); `adaptive.m_ref_l` |
| `k_loss` | Heat loss per °C above ambient | Holding power = k_loss × (setpoint − ambient); needs the cooling phase |
| `K = 1/k_loss` | Steady-state gain | Large K: heater dominates; steady state far above ambient |
| `τ = m·c/k_loss` | Thermal time constant | Larger batch = larger τ; the loop can afford slower response |
| `L` | Probe lag + filter delay | Limits tuning aggression; keep the probe well-immersed |
| `L/τ` | Relative dead time | < 0.1 easy; > 0.5 requires careful detuning |

### 9.5 PID tuning

Auto mode commands zero power until `pid.kp/ki/kd` are set. The script
prints SIMC-PI by default; `--rule zn|cc|all` adds the classical rules:

| Rule | Characteristic | When to use |
|---|---|---|
| **SIMC-PI** | Skogestad's IMC: `Kp = τ/(K(τc+L))`, `Ti = min(τ, 4(τc+L))`; τc sets speed vs. robustness | First choice for BIAB; tune τc with `--lambda` |
| **ZN-PID** | Aggressive, ~25 % overshoot | Reaction-curve rule; meaningless when `L ≪ τ` |
| **CC-PID** | Balanced at moderate `L/τ` | Same caveat as ZN |

The cap on the integral time is what makes SIMC usable here: an insulated
kettle has a `τ` of hours, and plain IMC-PI (`Ti = τ`) would leave the
integrator uselessly slow, while ZN/CC divide by `L/τ` and print absurd gains.
Keep `kd = 0`: at 60 Hz the raw per-sample derivative mostly amplifies sensor
noise.

#### Choosing τc (`--lambda`)

τc is the closed-loop time constant you ask for: after a small setpoint step
the error should decay roughly as `exp(−t/τc)`. It is the one knob in SIMC,
and on this plant the rule collapses to something you can read directly:

```
kp = m·c / (τc + L)          [W/°C]
Ti = 4 (τc + L)              [s]
P saturates when error > ramp_rate × (τc + L)     (ramp_rate = P_max / m·c)
```

So τc sets how far from setpoint the loop leaves full power and starts to
taper, and how fast the integrator can move. Smaller τc = stiffer:

| τc | kp (this kettle) | P tapers below | Ti | Character |
|---|---|---|---|---|
| L ≈ 10 s | 11 700 W/°C | 0.9 °C | 76 s | SIMC "tight": gain margin ≈ 3, phase margin ≈ 60°; every probe wobble becomes kilowatts |
| **30 s** (shipped) | 5 630 W/°C | 1.9 °C | 158 s | 2 °C step should settle within about 90 s; probe noise at hold ≈ 40 W rms of demand |
| 120 s (script default) | 1 720 W/°C | 6 °C | 518 s | 2 °C step took 4 min to first touch setpoint in the 2026-09-07 ramp test |

The 2026-09-07 ramp test at τc = 120 s showed why smooth is not the same as
safe: the response was gentle *and* overshot (0.26 °C on a 2 °C step, 0.73 °C
on 10 °C), because the long unsaturated approach let the integrator wind up
(§2.4). Integral separation (`pid.i_band_c`) removes that mechanism, and once
it is gone a smaller τc is pure gain. Robustness is what bounds it from below:
SIMC's τc = L is already a reasonable margin against model error, and the
things not in the model (the corner transients of §9.4, filter delay, a
grain bed changing the mixing) all argue for staying a factor of 2–3 above
it. The shipped 30 s ≈ 3L is that compromise. Batch size changes `m·c` and
therefore the right `kp` in proportion; that is what `adaptive.m_ref_l` is
for. Grain in makes the plant slower (more mass, worse mixing), which errs
on the safe side for a fixed gain set but still wants its own `[grain]`
gains.

The shipped `bibby.ini` carries SIMC-PI gains and feedforward identified from
the 2026-09-07 heat/cool test (45 L of water, 5000+5500 W nominal elements, no
grain). **Validate on your own setup before trusting a batch:**

1. Copy the printed `[pid]` (and `[feedforward]`, §9.6) blocks into
   `bibby.ini` and restart bibby.
2. Set a setpoint **5–10 °C above** current temperature, switch to **Auto**,
   and watch the charts.
3. A good response rises at full power, tapers over the last degree or two
   and settles with minimal overshoot. If it oscillates, increase τc
   (`--lambda`) and re-run the script; if it creeps up over minutes, or
   overshoots after a long approach, τc is too large or `pid.i_band_c` is off.
4. Inspect the logged `pid_ff_w`/`pid_p_w`/`pid_i_w`/`pid_d_w` split: the
   feedforward should carry the holding power, the integral only trim, the
   derivative not chatter.

Anti-windup itself needs no configuration: conditional integration plus the
`max_power/ki` backstop (§2.4) bound the integrator automatically. Two keys do:

- `pid.i_band_c` — integral separation. Keep it at about 0.5 °C (the shipped
  value) so the integrator stays out of the approach. The band should be a
  little larger than the steady-state ripple and any offset the feedforward
  leaves, and smaller than the error at which P leaves full power
  (`ramp_rate × (τc + L)` above), so the integrator wakes up only once the P
  term is already tapering.
- `pid.i_clamp_w` — how much power the integrator may ever add or remove,
  500 W as shipped. Size it from the model error you expect the integrator to
  cover, not from the elements: the feedforward supplies the holding power, so
  this only has to absorb a wrong `ambient_c`, a drifting `k_loss`, or a lid
  left off. Read `pid_i_w` from a good run and leave a few times its peak; if
  the log shows it sitting pinned at ±`i_clamp_w` while a real offset
  persists, the feedforward is wrong — fix `[feedforward]` rather than raising
  the clamp.

**Grain-in gains.** Adding grain changes the plant (more mass, worse mixing,
scorch risk at the bag). Re-run the heat/cool test with grain in (or a sacrificial
equivalent) to derive `grain.kp/ki/kd`, and consider `grain.max_power_w` to cap
flux at the bag.

**Adaptive scaling.** If batch size varies brew to brew, set
`adaptive.m_ref_l` to the batch the gains were tuned at *as the estimator
reads it* (the script prints it under `[adaptive]`; it is the fitted `m`,
not the litres poured) and enable `adaptive.enable`: kp/kd then scale with
the measured batch size within `[scale_min, scale_max]`.

### 9.6 Feedforward (optional, recommended)

A kettle spends most of a brew *holding* a temperature against heat loss. Left
to the PID alone, the integrator must wind up to supply that holding power —
slow to converge and a source of overshoot. The **holding feedforward**
supplies it directly:

```
ff_w    = clamp( (setpoint − ambient_c) / K , 0, max_power )   [watts]
demand  = clamp( ff_w + P + I + D , 0, max_power )
```

`K` (°C/W) and `ambient_c` live in `[feedforward]`; the same heat/cool test
that tunes the PID sizes the feedforward, and the script prints the block.
`process_gain_c = 0` disables it (the safe default).

- **It does not change loop stability.** `ff_w` depends on the *setpoint*, not
  the measurement, so it sits outside the feedback loop; the closed-loop
  dynamics are unchanged (superposition).
- **It does not cause overshoot** unless over-sized (K under-estimated). Keep K
  honest; a slight *under*-estimate of the holding power is the safe direction.
- **`k_loss` needs the cooling phase.** A heat-only log cannot separate `K`
  from `τ`; the script warns and tells you to leave `process_gain_c = 0`.
  This build ships with feedforward disabled for exactly that reason.
- `ambient_c` is the room temperature you passed as `--ambient`; the script
  copies it into the block. If the kettle habitually rests above room
  temperature (pump heat), the script's free-ambient cross-check will say so —
  use that value instead. Errors just become a small bias the integrator
  removes.

Feedforward is only active in auto mode, and an RTD fault still forces manual,
so it never drives the relays on bad data.

---

## 10. Data logging

`src/csv_logger.c` opens one timestamped file per run:

```
~/bibby/logs/YYYY/MM/DD/HH-MM-SS.csv
```

Directories are auto-created. In the default high-rate mode one row is written
per **fresh** sensor sample (~60 Hz), right after the control law runs, and
each row is flushed so a crash mid-brew keeps the data on disk. During a sensor
outage a row is still written every 0.5 s so the fault interval is on disk.
`logging.rate = low` drops to one row per `logging.low_period_s` for long
unattended runs. Columns:

```
wall_time, t_monotonic_s, temp_raw_c, temp_filt_c, setpoint_c,
p_demand_w, duty1, duty2, flux1_w_cm2, flux2_w_cm2,
pid_ff_w, pid_p_w, pid_i_w, pid_d_w, pid_integral, pid_deriv, pid_error_c,
m_est_l, manual, grain_in, rtd_fault, watchdog
```

- `p_demand_w` is the commanded power after every clamp (grain cap, flux cap).
  The sigma-delta modulator delivers it on average (§2.3), so it is also the
  delivered power — except while `watchdog` is 1, when the SSRs are held off.
  Logs written before 2026-09-13 carry an extra `p_delivered_w` column after
  it; the tools look columns up by name, so both kinds open.
- `flux1/2_w_cm2` are the per-element surface power densities from the split.
- `pid_*_w` is the feedforward / P / I / D breakdown in watts (§9.5);
  `pid_error_c` the residual error.
- `wall_time` is ISO-8601 local with milliseconds; `t_monotonic_s` is
  `CLOCK_MONOTONIC`. Recover `dt` from either.
- `grain_in` marks grain addition; `manual` the control mode; `rtd_fault` the
  raw MAX31865 fault byte; `watchdog` the ZC watchdog state.

`tools/plot_logs.py` is a small Tk browser for the log tree — pick a file,
tick columns, zoom. It reads whatever columns the header declares, so both old
and new logs open fine.

---

## 11. Repository layout

```
bibby/
├── CLAUDE.md                  project notes / coding conventions
├── CMakeLists.txt             build: bibby + tests, fetches LVGL
├── cmake/
│   └── embed_asset.cmake      turns the web page into a C byte array at build time
├── README.md                  this file
├── TODO.md                    known work not yet done (currently: HTTPS, §8)
├── bibby.ini                  user configuration (mains, elements, gains, cal)
├── deploy/
│   └── bibby.service          systemd unit (console unbind, memlock, RT prio)
├── docs/
│   ├── MAX31865.pdf           sensor datasheet
│   └── REBUILD.md             the plan the single-process rebuild followed
├── src/
│   ├── main.c                 startup, GPIO requests, thread spawn, shutdown
│   ├── state.{h,c}            shared atomics + chart history ring
│   ├── config.{h,c}           bibby.ini loader
│   ├── control.{h,c}          watts PID + feedforward
│   ├── power_split.{h,c}      equal-flux watts→duty split + flux cap
│   ├── sigma_delta.h          per-ZC sigma-delta modulator
│   ├── ssr_thread.{h,c}       ZC capture, SSR firing, watchdogs (SCHED_FIFO)
│   ├── sampler_thread.{h,c}   sensor pacing, filter, control, logging
│   ├── max31865.{h,c}         MAX31865 RTD driver
│   ├── temp_filter.{h,c}      boxcar cascade filter
│   ├── mass_estimator.{h,c}   online batch-size estimate (litres)
│   ├── csv_logger.{h,c}       per-run CSV logger
│   ├── single_instance.h      flock single-instance guard
│   ├── ui/
│   │   ├── lv_conf.h          LVGL configuration
│   │   ├── ui.{h,c}           LVGL init, fbdev + rotation, evdev touch, ui-test
│   │   ├── ui_screen.{h,c}    main screen: charts, slider, toggles, faults
│   │   ├── ui_kettle.{h,c}    kettle illustration with element glow
│   │   └── ui_theme.h         colors
│   └── web/                   optional web interface (§2.9), off by default
│       ├── web.{h,c}          HTTP server: threads, auth, routing
│       ├── http.{h,c}         request parsing, responses, Basic auth, buffers
│       ├── web_screen.{h,c}   framebuffer mirror, PNG encode, pointer injection
│       ├── web_logs.{h,c}     log listing, path validation, CSV decimation
│       ├── web_assets.h       declaration of the embedded page
│       └── www/index.html     the whole web UI (embedded into the binary)
├── tests/
│   └── test_units.c           unit tests for the pure modules
├── tools/
│   ├── identify_plant.py      heat/cool plant identification + PID tuning (§9.4–9.5)
│   ├── calibrate_sensor.py    §9.1/§9.2 calibration arithmetic
│   └── plot_logs.py           CSV log browser/plotter
└── pi_hat/bibby_pi_hat/       KiCad schematic + PCB + gerbers
```

---

## 12. License

bibby uses three licenses, one per artifact type:

| Artifact | License | File |
|---|---|---|
| Software (`src/`, `tests/`, `tools/`, `deploy/`) | Apache-2.0 | [`LICENSE`](LICENSE) |
| Hardware (`pi_hat/`) | CERN-OHL-P-2.0 | [`pi_hat/LICENSE`](pi_hat/LICENSE) |
| Documentation (`README.md`, `docs/`) | CC-BY-4.0 | [creativecommons.org/licenses/by/4.0](https://creativecommons.org/licenses/by/4.0/) |

**Apache-2.0** (software): permissive, includes an explicit patent grant so
techniques in the control code cannot be used against you or downstream users.
No per-file headers are required; the top-level `LICENSE` and `NOTICE` files
satisfy the license requirements.

**CERN-OHL-P-2.0** (hardware): the permissive variant of the CERN Open
Hardware Licence — the hardware analog of Apache/MIT. Covers the KiCad
schematics, PCB layout, and gerbers in `pi_hat/`.

**CC-BY-4.0** (documentation): attribution-only. You may reproduce, adapt,
and redistribute the documentation for any purpose as long as you credit the
original author.

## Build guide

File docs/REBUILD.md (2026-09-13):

\# bibby — Rebuild Specification (fresh start)

This is the one document needed to rebuild **bibby**, the brew-in-a-bag (BIAB)
temperature/power controller, from scratch with new code. It is written for an
engineer or AI starting cold. It states what to keep, what to change, and why.

The existing repository is still present and can be read for reference. The
**hardware is fixed** (the Pi HAT PCB, pinout, and sensor are not changing), and
several software pieces are proven and should be carried over close to
verbatim. Everything else is open to a cleaner design. This document calls out
each case.

Read it top to bottom once before writing any code.

---

## 0. Ground rules for the rewrite

These come from the project owner and override taste:

- **Language:** C by preference. C++ only where a library forces it, and then
  plain C++ — no templates, no clever generics. Never make the reader guess a
  type that isn't meant to be dynamic. Use fixed, explicit types.
- **Units:** SI / engineering units everywhere, including inside the control
  loop. Temperature in **°C**, power in **watts**, area in **cm²**, time in
  **seconds**. The display additionally shows temperature in **°F and °C**. Duty
  fraction `[0,1]` exists only at the actuator boundary (the SSR), not in the
  control law. (See §5 for the one deliberate unit choice.)
- **Structure:** small files, small functions, one responsibility each. No
  source file that crams several concerns together. Avoid abstraction that isn't
  paying for itself. If a function fits on a screen and reads top-to-bottom,
  prefer that over a framework.
- **Safety is the point.** This switches mains into multi-kilowatt elements. The
  default state of everything is **off**. Every safety mechanism in §4 is a
  requirement, not a feature.
- **2-space indent. `//` comments in C. `/* ... */` used when commenting a large block **

---

## 1. What the system does

Reads kettle temperature from a PT100 RTD, runs a temperature controller, and
delivers power to two mains heating elements through zero-cross solid-state
relays (SSRs). Power is modulated as a **duty cycle synchronized to the AC mains
zero crossing** (fire whole half-cycles, never phase-angle chop). A touchscreen
shows temperature and lets the user set a target, run manual or automatic
control, and watch the control behavior. Everything is logged to CSV for tuning.

Default target system: **BrewHardware "Premium Recirculating Electric (240 V)
BIAB Package — Get Tanked Edition, 20 gal"**, two heating elements, recirculated
(pumped) so the kettle is well mixed. The two-element, low-watt-density design
is the reason the power-split law in §6 matters.

---

## 2. Hardware — fixed, do not redesign

The Pi HAT PCB (`pi_hat/bibby_pi_hat/`, KiCad) and the pinout are **unchanged**.
Treat them as given. Read the schematic for the authoritative net list; the
sensor datasheet is at `docs/MAX31865.pdf`.

**Platform:** Raspberry Pi 5, 64-bit Raspberry Pi OS. GPIO chip is
`/dev/gpiochip4`. SPI is `/dev/spidev0.0`.

**Pin map (40-pin header):**

| Pin | GPIO | Signal | Dir | Role |
|---|---|---|---|---|
| 1 | — | 3.3 V | pwr | MAX31865 VIN |
| 6 | — | GND | pwr | MAX31865 GND |
| 19 | GPIO10 | SPI0 MOSI | out | MAX31865 SDI |
| 21 | GPIO9 | SPI0 MISO | in | MAX31865 SDO |
| 23 | GPIO11 | SPI0 SCLK | out | MAX31865 CLK |
| 24 | GPIO8 | SPI0 CE0 | out | MAX31865 CS |
| 36 | GPIO16 | DRDY | in | MAX31865 data-ready, active-low |
| 37 | GPIO26 | SSR2 | out | element 2 SSR drive |
| 38 | GPIO20 | Zero-cross | in | mains ZC pulse (rising edge) |
| 40 | GPIO21 | SSR1 | out | element 1 SSR drive |

**Front-end blocks on the HAT:**
- **RTD:** MAX31865 (PT100, 3-wire), 400 Ω 0.1 % reference resistor `Rref`
  (`R1`). Precision of `Rref` sets measurement accuracy and is a calibration
  anchor (§8).
- **Zero-cross:** H11AA1 AC-input optocoupler (anti-parallel LED — conducts on
  both half-cycles) with an RC/bias network; its output pulses at each mains zero
  crossing into GPIO20. Galvanically isolates mains sense from Pi logic.

**Safety-relevant hardware fact (verify before trusting §4):** GPIO21 and GPIO26
drive the SSR inputs directly — there is no external pull on those nets on the
HAT. On the Pi 5 these lines power up with the SoC **internal pull-downs**, so
before any software runs, and after the process releases the lines (normal exit
or crash), the SSR inputs read low → **elements off**. The whole single-process
safety argument leans on this. Confirm it on the bench (§11) and, if you ever
respin the HAT, add explicit external pull-downs on both SSR gates.

---

## 3. Architecture — one process, three concurrency domains

The previous build used **two processes** (a C relay controller and a C++
GUI/sensor frontend) talking through POSIX shared memory, specifically to keep
the safety-critical relay code isolated from the large GUI. That is allowed to
change. The owner's requirement is not "two processes" — it is that **three
activities run independently and none stalls the others**:

1. The **SSR modulator** runs off the zero-crossing edge, on its own timing.
2. The **RTD sampler** runs off the sensor's data-ready (DRDY) signal, on its
   own timing (edge interrupt or poll).
3. The **GUI** refreshes at its own rate, inhibited by neither of the above.

**Recommendation: a single binary with three threads.** This removes the shared
memory, the two-binary launch orchestration, the cross-process heartbeat, and an
entire class of "is the other process alive" logic — a large simplification that
the owner explicitly prioritizes. The isolation the two-process split bought is
replaced by the mechanisms in §4, which are sufficient because **process death
is already a safe state** (§2: lines released → pull-down → off).

```
  +--------------------------- bibby (one process) ----------------------------+
  |                                                                            |
  |  Thread A: SSR modulator          Thread B: RTD sampler     Main: GUI      |
  |  (real-time, SCHED_FIFO)          (blocks on DRDY edge)     (vsync-paced)   |
  |                                                                            |
  |  wait ZC edge (GPIO20) --------.  wait DRDY edge (GPIO16)   render frame    |
  |  sigma-delta -> fire SSR1/2    |  read MAX31865 -> °C       read snapshot   |
  |  ZC watchdog (no edge->off)    |  filter -> T_filt          draw UI + graph |
  |  control-stale watchdog        |  control law -> P_demand   handle touch    |
  |                                |  power split -> d1,d2       write setpoint, |
  |                                |  log row (rate-limited)     mode, manual   |
  |         ^        |             |        |        ^                 |        |
  |         |        v             |        v        |                 v        |
  |     [ duty1,duty2, heartbeat ]<+--------'   [ T, PID terms,   [ setpoint,   |
  |     [ output1/2, wdog, zc# ]---+----------> history buffer ]   mode, u_man, |
  |          in-process state (atomics + one mutex-guarded history)  sim_zc ]   |
  +----------------------------------------------------------------------------+
```

**Shared state** is a single in-process struct — the same idea as the old shared
memory, minus `shm_open`/`mmap`/`ftruncate` and minus IPC. Scalars are
`std::atomic` (or C11 `_Atomic`); the only compound shared object is the graph
history ring, guarded by one mutex. No lock-free queues, no message passing —
that would be over-abstraction for this data.

**Why threads, not processes, is safe enough here:**
- A crash in any thread ends the process; the OS releases the GPIO lines; the
  SSR inputs fall to their pull-down → off. Same end state the old two-process
  design relied on at boot and on double-fault.
- The SSR thread is tiny and runs at real-time priority (`SCHED_FIFO`), so GUI
  or GL stalls cannot delay a zero-cross response or the ZC watchdog.
- A **control-staleness watchdog** inside the SSR thread (see §4) forces duties
  to zero if thread B stops refreshing them — the in-process equivalent of the
  old cross-process frontend heartbeat.
- Optionally arm the Pi hardware watchdog (`/dev/watchdog`) petted from the SSR
  thread as a final backstop against a wedged process.

**Threading niceties (do these, they are cheap):**
- `mlockall(MCL_CURRENT|MCL_FUTURE)` at startup so the RT thread never page-faults.
- Set thread A to `SCHED_FIFO` at a modest priority; leave B and the GUI normal.
- Each thread opens the GPIO lines it owns (A: ZC + SSR1/2; B: DRDY). Different
  line offsets, so requests coexist on the one chip handle.

> **Note on a stale project memory.** An earlier note says "vsync off + 1 ms DRDY
> poll; don't re-enable vsync single-threaded." That constraint was a
> consequence of sampling on the single GUI thread. With sampling moved to its
> own thread (B) blocking on the DRDY edge, **the GUI can and should use vsync
> normally** — no busy-poll, no tearing, lower CPU. The old note does not apply
> to this architecture.

---

## 4. Safety requirements → mechanisms

Every row is a hard requirement. Implement all of them.

| Requirement | Mechanism |
|---|---|
| Elements **off at startup** | Drive both SSR GPIOs low as the first action, before the modulator runs. Duty state initializes to 0. |
| Elements **off on exit or crash** | `SIGINT`/`SIGTERM` handler drives SSRs low then exits; on any crash the OS releases the lines → pull-down → off (§2). |
| Elements **off if the mains-sense (ZC) signal is lost** | ZC watchdog in thread A: if no zero-crossing edge arrives within one mains half-period + 0.7 ms guard (≈9.0 ms @60 Hz, ≈10.7 ms @50 Hz), force both SSRs off and raise a `watchdog_alarm` flag. |
| Elements **off if control stops updating** | Control-staleness watchdog in thread A: thread B bumps a heartbeat counter each control update; if it does not advance for ~2 s worth of zero crossings, thread A forces duties to 0. |
| **No automatic temp control on unreliable temperature** | If the RTD reports any fault, force **manual** mode so the automatic control path cannot command power on bad data. Automatic mode is only reachable with a healthy sensor. |
| **Bounded commands** | Clamp per-element duty to `[0,1]` at the SSR boundary and clamp `P_demand` to `[0, P1+P2]` in the control path. |
| **One instance only** | `flock` single-instance guard on a lockfile at startup (kernel releases it on any exit). One binary now, so one lock. |
| **Bench testing without mains** | A `simulate_zc` flag makes thread A treat its ZC-watchdog timeout as a zero crossing, so the modulator and UI run with no AC connected. |

**Zero-cross simulation caveat:** when `simulate_zc` is set, the ZC-lost watchdog
must be suspended (a simulated edge is, by definition, "no real edge"). Keep this
path obviously separate from the live path so it can never mask a real ZC loss
during a brew. The visibility/enablability of the simulate ZC button will be in the INI config, so it can be removed after initial hardware checkout.

---

## 5. The one deliberate unit choice: watts inside the loop

Keep the control law in engineering units. The controller consumes temperature
in **°C** and produces a **power demand in watts** `P_demand ∈ [0, P1+P2]`. This
is physically clean:

```
  Kp [W/°C] · error [°C] = [W]           proportional term is a power
  feedforward [W]                        holding power to fight heat loss
  process gain K [°C/W] = 1/h            identified from a step test (§8)
```

Duty fraction `[0,1]` appears only downstream, at the SSR, where it belongs. The
`[0,1]` value is an actuator command, not a control quantity, so it does not
live in the loop. This satisfies "engineering units even inside the PID."

The one place `[0,1]` is unavoidable is the sigma-delta modulator, which by
definition schedules a *fraction* of half-cycles. That is a hardware detail
below the control law, not part of it.

---

## 6. Control chain, end to end

```
 RTD ─► MAX31865 ─► CVD+cal ─► filter ─► control law ─► power split ─► sigma-delta ─► SSRs
        (§7)        (°C)       (°C)      (°C ➜ W)        (W ➜ d1,d2)    (d ➜ fired)    (§7)
```

Stage by stage:

1. **MAX31865 → °C** (§7): non-blocking read, Callendar–Van Dusen, per-unit
   calibration. Carry over from the existing driver.
2. **Filter:** the existing `SecondOrderAverage` (two cascaded N-sample boxcars
   = triangular-weighted CIC) is fine; keep it. Primes on the first sample so it
   starts at the true value. Group delay ≈ `N/f_s` feeds into the dead-time term
   for tuning (§8).
3. **Control law (°C → W):** PID on `error = setpoint − T_filt`, run once per
   fresh sample, output clamped to `[0, P1+P2]` watts. Add an optional
   **holding feedforward** in watts: `u_ff = (setpoint − ambient) / K`, the
   steady-state power to hold the setpoint against heat loss, so feedback only
   trims model error. Anti-windup by **conditional integration** (hold the
   integrator when the output is already railed and the error pushes further into
   the rail). This mirrors the proven logic in the old `pid.cpp`; only the units
   change (duty → watts) and the clamp bound becomes `P1+P2`. 
   In addition, there is a second PID mode "grain in." When the grain is in, the PID will have a different set of coefficients, and the heating elements have a lower peak output wattage.
4. **Power split (W → per-element duty):** §6.1. This is the new intermediate
   function the owner asked for.
5. **Sigma-delta (duty → fired half-cycles):** §7. Carry over unchanged.

Manual mode bypasses stages 3–4: the slider commands a power (or a duty) that
feeds the split / the SSRs directly.

### 6.1 Power split — minimize surface power density (anti-scorch)

Two elements with rated power `P1,P2` (W) and wetted area `A1,A2` (cm²). Given a
demanded power `P_demand`, choose per-element power `x1,x2` (then duty
`di = xi/Pi`) to **minimize the peak surface power density** `xi/Ai` — high flux
is what scorches wort onto the element.

Minimizing the maximum of `x1/A1, x2/A2` subject to `x1+x2 = P_demand` puts both
fluxes **equal** (spread the load over all available area):

```
  x_i = P_demand · A_i / (A1 + A2)        // equal flux on both elements
  d_i = x_i / P_i
```

Then handle saturation (one element hitting `di = 1` before the other):

```
  A  = A1 + A2
  x1 = P_demand * A1 / A
  x2 = P_demand * A2 / A
  if (x1 > P1) { x2 += x1 - P1; x1 = P1; }   // push overflow to the other
  if (x2 > P2) { x1 += x2 - P2; x2 = P2; }
  x1 = clamp(x1, 0, P1);  x2 = clamp(x2, 0, P2);
  d1 = x1 / P1;  d2 = x2 / P2;
```

Properties worth knowing:
- For **identical elements** (`P1=P2, A1=A2`) this gives `d1 = d2 =
  P_demand/(P1+P2)` — i.e. both elements at the same duty, which is exactly what
  the old code did. The new law is the general case that also handles unequal
  elements correctly.
- Total deliverable power is `P1+P2`; clamp `P_demand` there.
- **Optional scorch cap:** add `element.max_flux_w_cm2` to config. If set, cap
  `P_demand ≤ max_flux · (A1+A2)` so the nominal (equal-flux) case never exceeds
  the limit. BrewHardware's ultra-low-watt-density elements exist precisely to
  keep flux low; a configurable cap in W/cm² lets the controller honor that in
  engineering units. Keep it optional (0 = disabled).

Put this in its own file (`power_split.{h,c}`), pure function, no state, trivially
unit-testable.

---

## 7. Modules to carry over (proven — port, don't reinvent)

Port these with minimal changes. They are correct and were validated on the
hardware. However, restructuring to make code cleaner is encouraged.

**MAX31865 driver** (`sensors/max31865`):
- SPI `/dev/spidev0.0`, 1 MHz, `SPI_MODE_1`. PT100, 3-wire, 400 Ω `Rref`.
- Init order (datasheet-mandated): write config with 3-wire + fault-clear +
  **mains-notch filter bit** (bit0: set=50 Hz, clear=60 Hz) → enable VBIAS, wait
  10 ms → enable auto-conversion → discard the first couple of conversions using
  DRDY. The notch bit must be set **before** auto-conversion.
- `read_temperature()` is **non-blocking**: check DRDY; if not ready return the
  last value flagged not-fresh. If ready, burst-read RTD + fault registers,
  convert via Callendar–Van Dusen, apply per-unit gain/offset (§8), return fresh.
- **Fault handling:** check the RTD-LSB fault bit and the Fault Status register
  every read; reject a faulted conversion (hold the last good value so the filter
  is not poisoned), clear the latch, and expose a decoded fault string for the UI.
- In the new design, thread B can **block on the DRDY falling edge** (libgpiod v2
  edge event) instead of polling — cleaner and it decouples sampling from the GUI
  entirely. Keep the non-blocking `read_temperature` too; it is still useful.

**Sigma-delta ZC modulator** (into thread A): each zero crossing, add the
per-channel duty to an accumulator; when it reaches 1.0, fire that SSR for the
half-cycle and subtract 1.0; cap the accumulator at 2.0 to bound catch-up. This
is a first-order delta-sigma DAC clocked by the mains — average fired fraction
equals commanded duty, switching energy pushed to high frequency. Carry over
verbatim.

**Temperature filter** (`temp_filter`): keep structure of `SecondOrderAverage` default as-is. Equivalent to a second order CIC filter. Have filter filter order and length be options in the INI.

**INI config loader** (`config`): keep the tiny section/key parser, defaults, and
`$BIBBY_CONFIG` lookup. Extend the key set (§9).

**Single-instance flock** (`single_instance`): keep.

**Calibration methodology** (README §8/§9 of the old README): the ice-point
`Rref` trim and two-point span gain/offset procedure are sound and per-unit.
Carry the method over; the only change is that the identified **process gain K is
now °C/W** (= 1/h), not °C per unit duty (§8). Note: please evaluate whether a new calibration method is better.

---

## 8. Calibration & tuning (methodology carries over, units change)

This has not been actually verified and ran with real hardware. Evaluate if this is the best method.

**Sensor calibration** (per probe + board, unchanged in method):
1. `Rref` ice-point one-point trim: `Rref = Rref_nom · 100.0 / R_pt100(T_ice)`.
2. Two-point span: `T_true = gain·T + offset` from two reference points (ice
   point and altitude-corrected boiling point are the cheap, wide-span choices).
All three live in `[sensor]` in the INI; identity defaults leave the sensor
uncalibrated but functional. (Full worked procedure is in the old README §9 —
reuse it.)

**Plant model & PID tuning** — same open-loop step-test method, re-expressed in
watts:
- The plant is well approximated as First-Order-Plus-Dead-Time:
  `G(s) = K·e^(−Ls)/(τs+1)` with `K` in **°C/W**, `τ` the kettle time constant
  (tens of minutes for this batch size), `L` the effective dead time (probe lag
  + filter group delay). `L/τ` is small for a big kettle — the challenge is the
  slow time constant, not dead time.
- `tools/identify_plant.py` fits `K, τ, L` from a constant-power step and prints
  PID gains. **Update it** so:
  - the step power it fits against is `duty · (P1+P2)` in watts (it already knows
    the duty and can read the wattages from the INI),
  - it reports `K` in °C/W and gains in W-based units (`Kp` in W/°C, etc.),
  - it prints a ready-to-paste `[feedforward] process_gain_c` (= K, °C/W) and a
    suggested `ambient_c`.
- Prefer **IMC-PI** with `λ ≈ L` (or larger for a mash — overshoot costs enzyme
  activity). ZN/Cohen-Coon offered as alternatives.
- The controller accumulates raw error per sample (`integral += error`, deriv =
  `Δerror`), so the discrete INI gains fold in the sample period `T_s`:
  `ki_ini = Ki_c·T_s`, `kd_ini = Kd_c/T_s`, `kp_ini = Kp_c`. `T_s` is recovered
  from the log's monotonic timestamp column. Keep this convention documented.

---

## 9. Configuration (INI) — one file, no recompiles

Everything another person/setup would change stays in `bibby.ini`, loaded at
startup. Carry the old keys, add the watts/logging ones. Missing keys fall back
to safe defaults (elements off-capable, PID gains zero → auto commands zero
power until tuned).

```ini
[mains]
frequency_hz = 60            ; 50 or 60; sets ZC watchdog timeout + sensor notch

[element1]                   ; SSR1, GPIO21 / pin 40
watts    = 5000              ; rated power, W  — CONFIRM against your package
area_cm2 = 820               ; wetted surface area, cm² — MEASURE/estimate
[element2]                   ; SSR2, GPIO26 / pin 37
watts    = 5500
area_cm2 = 473

[power]
max_flux_w_cm2 = 0.0         ; optional anti-scorch cap; 0 = disabled (§6.1)

[pid]                        ; control law; output is WATTS now (§5)
kp = 0.0                     ; W/°C   (zero until tuned)
ki = 0.0
kd = 0.0

[feedforward]                ; holding power feedforward (§6, §8)
process_gain_c = 0.0         ; identified K, °C/W; 0 disables feedforward
ambient_c      = 20.0        ; cold-start/room reference, °C

[sensor]                     ; per-unit RTD calibration (§8)
ref_resistor_ohms = 400.0    ; MAX31865 Rref, ice-point trimmed
temp_cal_gain     = 1.0
temp_cal_offset   = 0.0

[logging]
rate = high                  ; "high" = every sample (tuning); "low" = decimated
low_period_s = 2.0           ; row interval when rate=low
```

> The default element wattage/area above are **placeholders to confirm** against
> the actual Get Tanked package and a physical measurement — the control math is
> independent of the exact numbers, but the feedforward and flux cap are not.

The mains frequency still drives: the ZC-watchdog timeout (half-period + 0.7 ms
guard), the control-staleness count (~2 s of ZC), and the MAX31865 notch bit.

---

## 10. UI

**Requirement:** touchscreen, mounted sideways (portrait panel, landscape use —
the old build rendered portrait then rotated 90° CW and remapped touch). The GUI
must refresh independently of sampling and modulation (satisfied by §3: it is its
own thread). ImGui is **not** required.

**Recommendation: LVGL** for the rewrite, with the proven **SDL3 + Dear ImGui +
GLES3** stack as the safe fallback.

- **LVGL** is a C library purpose-built for embedded touchscreen HMIs. It gives:
  native display **rotation** (a config flag — no hand-written FBO + rotation
  shader), native touch input, and retained-mode widgets including a **chart**
  widget that fits the PID graph (§10.1). Choosing it keeps the **entire
  application in C**, matching the owner's language preference and collapsing the
  C/C++ split. Backend on the Pi: LVGL over SDL (easy) or DRM/KMS + evdev.
- **ImGui fallback** is proven on this exact hardware, and the rotation +
  touch-remap are already solved in `frontend/display.cpp` and `main.cpp`. It is
  C++, and it needs the manual rotation. Use it if LVGL integration on the panel
  proves troublesome — the UI is not where the project's value is, so do not sink
  days into a toolkit.

Either way, keep UI code out of the control and safety paths. The UI only
**reads** a state snapshot and **writes** setpoint / mode / manual command /
`simulate_zc` / `grain_in`.

**Screen contents** (carry the old layout intent):
- Large readout: setpoint (°C) and measured temperature in **both °C and °F**.
- Element indicators that track each SSR's fired state.
- Full-height duty/power control, active only in manual mode. Have PID output update the display for this control (looks nice) even though it is disabled.
- Setpoint steppers (±10 / ±1 / ±0.1 °C).
- Toggles: **Manual Control**, **Test Touch** (simulate ZC, rename buttont o ZC Sim, don't display if INI config says to not display), **Grain In** (logged
  event marker).
- The PID graph (§10.1).
- A fault band: decoded RTD fault and watchdog alarm when active. When a fault
  forces manual mode, say so on screen.

### 10.1 The PID graph — plot more than temperature

For tuning you need to *see the loop*, not just the temperature. Plot, sharing a
time axis (last few minutes, scrolling):

- **Setpoint** and **filtered temperature** (and optionally **raw** temperature,
  lighter, to judge noise vs. filter lag).
- **Error** (`setpoint − T`) — the quantity the loop actually acts on.
- **Total commanded power** `P_demand` (W), and the **per-element duties** `d1,
  d2` — so you can watch the split and saturation.
- **PID term breakdown:** feedforward, P, I, D contributions (in W). This is the
  single most useful tuning view — it shows whether the integrator is doing the
  holding work (it should not, if feedforward is sized right), whether D is just
  amplifying noise, and how the terms trade off during a transient.
- **SSR fired state**, to confirm the modulator is tracking the command.
- **Event markers:** grain-in, mode changes, setpoint changes — align brew events
  to the trace.

Practical: a two-pane graph (temperature/setpoint on top, the power/term
breakdown below, shared X) reads better than one crowded axis. LVGL's chart or
an ImGui draw-list plot both do this. Feed it from the same per-sample data the
logger writes, so the on-screen graph and the CSV never disagree.

### 10.2 Manual / auto and the fault interlock

- **Manual:** the on-screen control drives the elements (through the §6.1 split
  or directly). Always available.
- **Auto:** the control law drives them. Reachable **only** with a healthy
  sensor; any RTD fault forces manual (§4) and the UI shows why.

---

## 11. Logging — high rate and low rate

One timestamped CSV per run, `~/bibby/logs/YYYY/MM/DD/HH-MM-SS.csv`, directories
auto-created, each row `fflush`ed so a crash keeps the data. Written from thread
B, which has the fresh sample and the current control terms.

**Two rates** (owner requirement):
- **High** — one row per fresh sample (~50–60 Hz). Used while **tuning** and for
  the plant-ID step test; nothing is decimated.
- **Low** — decimated to `low_period_s` (default ~1–2 s). Used for **normal
  brewing** after tuning, to keep files small over a multi-hour brew.

Selected by `[logging] rate` in the INI. The user should use high for tuning, flip to low once dialed in). Implement as a
simple time-based decimator on the write path — same row format either way, only
the interval changes. Do not fork the schema.

**Columns** (superset of the old set, in engineering units):

```
wall_time, t_monotonic_s, temp_raw_c, temp_filt_c, setpoint_c,
p_demand_w, duty1, duty2, flux1_w_cm2, flux2_w_cm2,
pid_ff_w, pid_p_w, pid_i_w, pid_d_w, pid_integral, pid_deriv,
pid_error_c, manual, grain_in, rtd_fault, watchdog
```

- `wall_time` ISO-8601 local w/ ms; `t_monotonic_s` a monotonic clock — recover
  `dt` from either.
- Keep the P/I/D/feedforward breakdown; it is what §8 tuning consumes.
- `flux*_w_cm2` (= `d_i·P_i/A_i`) make the anti-scorch behavior directly visible.

---

## 12. Suggested file layout

Small, single-purpose files. One binary. Illustrative, not prescriptive:

```
bibby/
├─ bibby.ini
├─ src/
│  ├─ main.c                 startup: config, threads, safe-state, teardown
│  ├─ state.h                shared in-process state (atomics) + history mutex
│  ├─ ssr_thread.c/.h        thread A: ZC edge, sigma-delta, both watchdogs
│  ├─ sampler_thread.c/.h    thread B: DRDY edge, read, filter, control, split, log
│  ├─ control.c/.h           PID (°C → W), feedforward, anti-windup
│  ├─ power_split.c/.h       W → (d1,d2), equal-flux + optional flux cap (§6.1)
│  ├─ sigma_delta.c/.h       duty → fired half-cycle decision
│  ├─ max31865.c/.h          RTD driver (ported)
│  ├─ temp_filter.c/.h       SecondOrderAverage (ported)
│  ├─ csv_logger.c/.h        dual-rate CSV (§11)
│  ├─ config.c/.h            INI loader (ported + new keys)
│  ├─ single_instance.h      flock guard (ported)
│  └─ ui/                    LVGL (or ImGui) UI, isolated from control
├─ tools/identify_plant.py   plant ID + tuning (watts update, §8)
├─ pi_hat/                   UNCHANGED KiCad project
└─ docs/MAX31865.pdf
```

If the UI stays ImGui/C++, only the `ui/` subtree and its objects are C++; the
whole control/safety core stays C.

---

## 13. Build & deploy

- **CMake**, out-of-source. One executable. Link `gpiod` and `rt`; plus the UI
  toolkit (LVGL, or SDL3-static + GLESv2 for the ImGui fallback).
- `libgpiod v2` is required (v2 edge-event API). Enable SPI (`/dev/spidev0.0`).
- Keep `build/` and `logs/` gitignored; keep `bibby.ini` checked in.
- Make the config path and any asset paths **runtime-resolvable** (resolve
  `/proc/self/exe`, look next to the binary, honor `$BIBBY_CONFIG`) so an
  installed binary works — do not bake build-tree paths as the old build did.

**Autostart at boot (systemd).** One binary now, so one unit. The RT thread needs
scheduling privilege and the process needs GPIO/SPI access.

```ini
# /etc/systemd/system/bibby.service
[Unit]
Description=bibby brew controller
After=multi-user.target

[Service]
User=ramp
SupplementaryGroups=gpio spi video render input
AmbientCapabilities=CAP_SYS_NICE          # allow SCHED_FIFO on the SSR thread
Environment=BIBBY_CONFIG=/home/ramp/bibby/bibby.ini
ExecStart=/home/ramp/bibby/build/bibby
Restart=on-failure
RestartSec=3

[Install]
WantedBy=multi-user.target
```

```
sudo systemctl daemon-reload
sudo systemctl enable --now bibby
journalctl -u bibby -f
```

`CAP_SYS_NICE` (or a matching `LimitRTPRIO`) lets the SSR thread take real-time
priority. On exit/kill, the process drives SSRs low and the OS releases the lines
regardless (§4). If you enable the hardware watchdog, make sure the unit's
restart policy and the watchdog timeout are consistent.

---

## 14. Bring-up & test plan

Do these in order; do not connect mains until the bench tests pass.

1. **Build & run headless-safe.** Confirm single-instance lock, config load, and
   that SSR GPIOs read low before and during startup (meter the SSR gate lines).
2. **Sensor.** Verify DRDY toggling and sane °C in air; unplug an RTD wire and
   confirm the fault is detected, the value is held, and the UI shows the decoded
   fault. Confirm a fault **forces manual mode**.
3. **ZC simulation.** With **no mains**, enable `simulate_zc`; confirm the
   modulator fires the SSR gate lines at commanded duty (scope or LED), and that
   the ZC-lost watchdog stays *quiet* while simulating and *trips* (SSRs off,
   alarm) when you disable simulation with no real ZC present.
4. **Control-staleness watchdog.** Pause thread B (or stub it) and confirm thread
   A zeroes the duties within ~2 s.
5. **Crash-safety.** `kill -9` the process mid-fire; confirm the SSR gates fall
   low immediately (this is the pull-down path from §2 — verify it physically).
6. **Live, low power.** Only now connect mains through properly rated SSRs,
   fusing, and earth bonding. Verify real zero crossings drive `iteration`,
   run a low manual duty, watch the temperature respond.
7. **Plant ID → tune.** Run the §8 step test at high log rate, fit with
   `identify_plant.py`, paste gains + feedforward, validate in auto, then switch
   logging to low rate for real brews.

---

## 15. Decisions to confirm before coding

Most choices here are made and justified. Three are worth an explicit yes/no from
the owner, because they shape the whole rewrite:

1. **Single process, three threads** (§3) instead of two processes + shared
   memory. Recommended for simplicity; safety is preserved by §4 and the
   pull-down-off property (§2). Confirm §2's pull-down on the bench early — the
   argument depends on it.
2. **UI toolkit: LVGL** (all-C, native rotation/touch/chart) vs. keeping the
   proven **SDL3+ImGui** stack (§10). Recommended LVGL; ImGui is the low-risk
   fallback.
3. **Control output in watts** with a downstream power-split (§5, §6). Recommended
   for SI-unit cleanliness and correct handling of unequal elements; it changes
   the PID gain units and a few lines of `identify_plant.py`.

Everything else in this document is a direct port or a stated requirement.
```

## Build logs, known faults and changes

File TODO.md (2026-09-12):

# bibby — TODO

Work that is understood but not done. Each entry should carry enough context to
be picked up cold: what, why, and what was already ruled in or out.

---

## HTTPS for the web interface

**Status:** not started. The web interface (README §2.9, §8) serves plain HTTP,
so its HTTP Basic password crosses the LAN in the clear — it is base64, not
encryption. Everything else about the feature is done.

**Why it matters.** The password is the only authorization on a browser that
can drive the panel. Home Wi-Fi already encrypts the air link (WPA2/WPA3), so
the realistic exposure is another device on the LAN or the wired segment, not a
passer-by. Secondary but real wins: browsers stop flagging the page as insecure,
and password managers will offer to save the credential. The biggest gain is
that Basic auth stops being the weak link — over TLS it is a reasonable scheme.

**Today's workaround**, already documented in README §8: `web.bind = 127.0.0.1`
plus `ssh -L 8080:localhost:8080 ramp`. Strong crypto, zero new code, but
awkward from a phone.

### The code is the easy part (~200 lines)

All socket I/O goes through three call sites:

| Location | Call |
|---|---|
| `src/web/http.c` `http_read_request()` | `recv()` for headers |
| `src/web/http.c` `http_read_request()` | `recv()` for the body |
| `src/web/http.c` `http_send_all()` | `send()` |

(The `read()` in `http_respond_file()` is the log file, not the socket — it
already goes out through `http_send_all`.)

So the shape is: add an `SSL *` to `HttpReq`, route those three through a
dispatch on whether TLS is active, create the `SSL_CTX` in `web_start()`, and
do `SSL_new` / `SSL_accept` / `SSL_shutdown` / `SSL_free` per connection in
`conn_main()`. New config keys alongside the existing `[web]` block:
`tls_cert`, `tls_key` — absent means plain HTTP, matching how an absent
password already disables the server entirely.

Notes for whoever does it:

- OpenSSL 3.5.7 is already on the Pi; `apt install libssl-dev` for the headers,
  then link `OpenSSL::SSL` in `CMakeLists.txt`.
- Since OpenSSL 1.1.0 the library is thread-safe for distinct `SSL` objects, so
  the thread-per-connection design needs no locking callbacks.
- The one subtle part: the connection sockets carry `SO_RCVTIMEO` (30 s), and a
  socket timeout surfaces from OpenSSL as `SSL_ERROR_WANT_READ`, not an error.
  Handshakes need their own timeout so a client that opens a socket and says
  nothing cannot hold a thread.
- Performance is a non-issue. The Pi 5 has ARM crypto extensions and measures
  2.28 GB/s AES-128-GCM (`openssl speed -evp aes-128-gcm`); the screen mirror
  at 5 fps is 240 kB/s.

### Certificates are the real work

This is the decision to make first — the code follows from it.

| Approach | Effort | Result |
|---|---|---|
| Self-signed | ~10 min | Warning screen on every device, every browser |
| **Local CA** (mkcert, or plain openssl) | ~1 h + per-device trust install | Clean padlock, 10-year cert, no renewals |
| Let's Encrypt via DNS-01 | ~half day | No warnings anywhere, but needs a domain you own, outbound internet, and 90-day renewal automation on an appliance |
| Reverse proxy (Caddy/nginx/stunnel) | ~30 min config, no C | Sidesteps all of the above, but adds a daemon and a failure mode, and gives up the single-binary property |

The Pi runs `avahi-daemon` and answers to **`ramp-controller.local`**, so issue
the certificate against that name rather than `192.168.1.40` — it then survives
a DHCP change.

**Recommendation:** in-process OpenSSL with a local CA, keeping plain HTTP
working when no cert is configured. Budget about a day including testing. The
unavoidable annoyance is installing the CA root on each device: iOS needs a
configuration profile *and* a separate trust toggle buried in Settings, and
Firefox on Android keeps its own trust store separate from the system one.

**When it lands,** update README §2.9 and §8 (which currently tell the operator
plainly that traffic is unencrypted), the `[web]` comment block in `bibby.ini`,
and the safety note in `CLAUDE.md`.

---

## Approach mode: full power to setpoint, then cut to feedforward

**Status:** not started. Proposed after the 2026-09-07 ramp test
(`logs/2026/09/07/18-59-53.csv`), alongside the two changes that did land
from that analysis: integral separation (`pid.i_band_c`) and the retune to
τc = 30 s. Those two fix the overshoot; this item is about getting to
setpoint faster than a tapering P term ever can.

**The idea, in full.** When the error exceeds a configured threshold, command
full power (or the grain-in power cap while Grain In is on), hold the
integrator at zero, and cut to feedforward-only when the predicted coast
reaches the setpoint, then hand control to the PI. Above `max_power / kp` of
error the PI already commands full power, so the real addition is the *cut*
rule: switch to holding feedforward when the temperature will coast onto the
setpoint, instead of letting the P term taper the last couple of degrees.
The coast is best predicted from the measured slope times the dead time
(`dT/dt × L`, with the slope taken over roughly the last 10 s of the filtered
temperature) rather than from the batch-size estimate, because the slope is
available immediately, includes heat loss, and does not depend on the
estimator having converged. The batch-size estimate (`m_est_l`) is still
worth using for a time-to-setpoint readout on the UI and as a cross-check on
the slope. With `kp = 5633 W/°C` the P term tapers from full power below
1.9 °C of error; at the measured 2 °C/min full-power ramp that taper costs
about a minute per step, which is what this mode would save.

**Findings to design against** (from the 2026-09-07 heat/cool log,
`logs/2026/09/07/15-41-11.csv`):

- Dead time is ~9.5 s: the reading starts rising 9 to 12 s after power-on.
- After a hard cut from ~7.7 kW at 1.9 °C/min the reading coasted up
  +0.2 °C, peaking 12 to 15 s after the cut. Slope × L predicts +0.3 °C, so
  the prediction is conservative by about a third.
- After that peak the reading *sagged* 0.3 °C over the next two minutes as
  the stratified layer around the probe collapsed once the element plume
  stopped (the identification script calls this the mixing offset). So the
  cut point should be about 0.2 °C below setpoint, and the PI must then
  recover a 0.3 °C sag promptly, which the τc = 30 s gains can do.

**Shape of the implementation.** A small state machine in
`src/sampler_thread.c` ahead of `pid_update()`: `APPROACH` entered when
`error > approach.engage_c` in auto mode and not faulted; while in it,
`p_demand = out_max_w`, `pid_reset()` each pass so the integrator stays at
zero, and a slope estimator over the last N samples of `temp_filt`; exit to
`TRACK` (plain PI) when `temp_filt + slope × approach.coast_s >= setpoint -
approach.margin_c`, or if the operator drops the setpoint below the current
temperature, or on any fault (the existing interlock already forces manual).
New `[approach]` keys in `bibby.ini`: `enable`, `engage_c`, `coast_s`
(default L from the identification), `margin_c`, all documented in README §7
and §9. Log the mode (a new CSV column or a value in `manual`-style flags)
so the cut can be checked in `tools/plot_logs.py`. Unit-test the state
machine with a synthetic ramp. Safety: this mode commands nothing the PI
cannot already command (full power is the existing clamp), and every
existing interlock runs ahead of it, so it adds no new failure mode.

---

**Grain In profile** Do we need it
I read the following in the README:
"Grain in makes the plant slower (more mass, worse mixing), which errs on the safe side for a fixed gain set but still wants its own [grain] gains."
First of all, the plant from a control standpoint is actually a hybrid. Most of the flow happens in the shallow area below the false bottom, and i expect the mass estimate to go low and the temp to more quickly servo. But, a fraction of the water is recirculated from the top and pushed down into the temp controlled area. I expect the integrator to do the work here tracking the needed heat to keep the new flowing wort in at good temp control until, eventually, the grain is actually at the right temp, at which point the integrator will need to lower.
However, i wonder if the new profile is even needed at all considering the mass estimator is working correctly...however, the mass estimator needs a step command in temp to work reasonably. Perhaps we need a separate pid tuning with a lower mass (just above the grain bed of water to emulate).

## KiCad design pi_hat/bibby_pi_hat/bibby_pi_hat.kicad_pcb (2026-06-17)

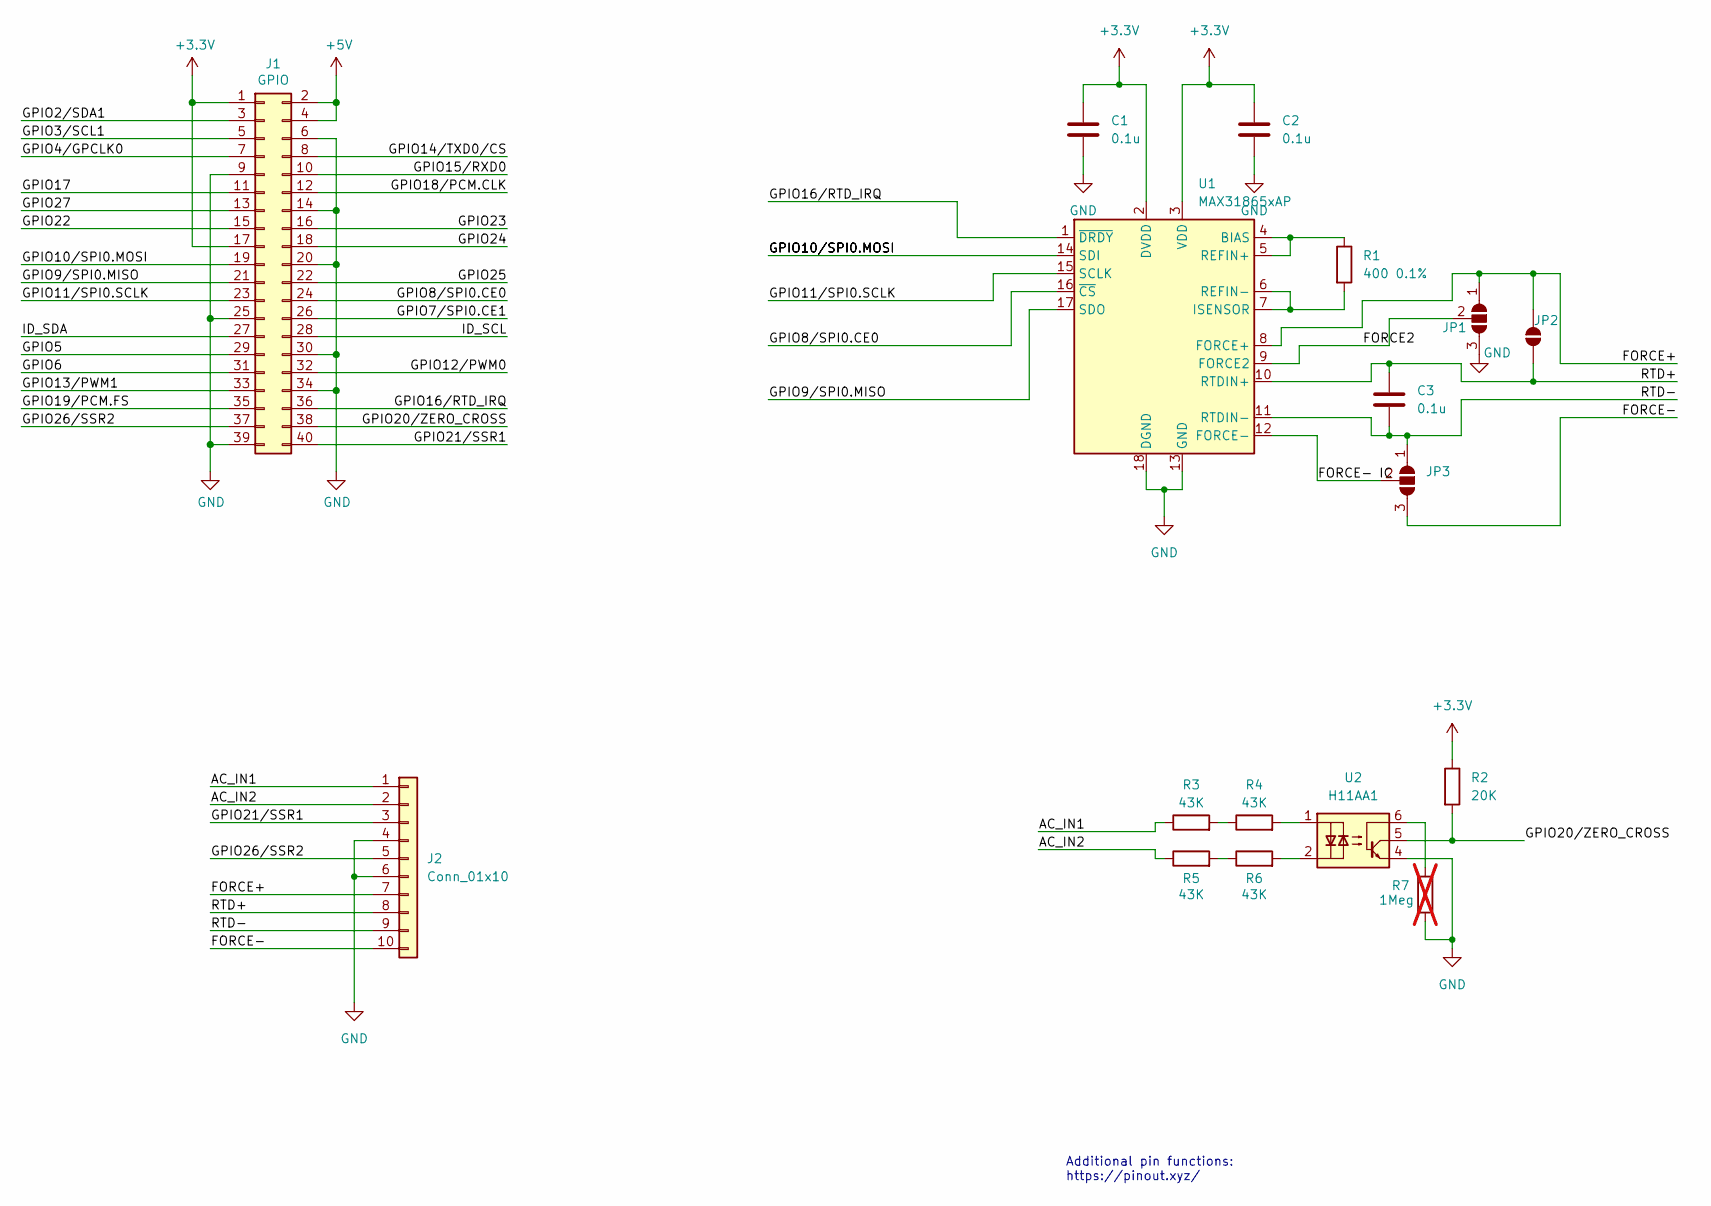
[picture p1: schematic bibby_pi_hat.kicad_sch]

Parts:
C1, C2, C3: 0.1u; C_0603_1608Metric_Pad1.08x0.95mm_HandSolder
J1: GPIO; PinSocket_2x20_P2.54mm_Vertical
J2: Conn_01x10; TerminalBlock_Phoenix_MKDS-1,5-10-5.08_1x10_P5.08mm_Horizon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
JP1, JP3: SolderJumper_3_Open; SolderJumper-3_P2.0mm_Open_TrianglePad1.0x1.5mm_NumberLabels
JP2: SolderJumper_2_Open; SolderJumper-2_P1.3mm_Open_TrianglePad1.0x1.5mm
R1: 400 0.1%; R_0603_1608Metric_Pad0.98x0.95mm_HandSolder
R2: 20K; R_0603_1608Metric_Pad0.98x0.95mm_HandSolder
R3, R4, R5, R6: 43K; R_0603_1608Metric_Pad0.98x0.95mm_HandSolder
R7: 1Meg; R_0603_1608Metric_Pad0.98x0.95mm_HandSolder; not fitted
U1: MAX31865xAP; SSOP-20_5.3x7.2mm_P0.65mm
U2: H11AA1; DIP-6_W7.62mm

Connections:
+3.3V: C1.1, C2.1, J1.1, J1.17, R2.1, U1.2 (DVDD), U1.3 (VDD)
+5V: J1.2, J1.4
/AC_IN1: J2.1, R3.1
/AC_IN2: J2.2, R5.1
/FORCE2: JP1.2 (C), U1.9 (FORCE2)
/FORCE+: J2.7, JP1.1 (A), JP2.2 (B), U1.8 (FORCE+)
/FORCE-: J2.10, JP3.3 (B)
/FORCE- IC: JP3.2 (C), U1.12 (FORCE-)
/GPIO2/SDA1: J1.3
/GPIO3/SCL1: J1.5
/GPIO4/GPCLK0: J1.7
/GPIO5: J1.29
/GPIO6: J1.31
/GPIO7/SPI0.CE1: J1.26
/GPIO8/SPI0.CE0: J1.24, U1.16 (~CS)
/GPIO9/SPI0.MISO: J1.21, U1.17 (SDO)
/GPIO10/SPI0.MOSI: J1.19, U1.14 (SDI)
/GPIO11/SPI0.SCLK: J1.23, U1.15 (SCLK)
/GPIO12/PWM0: J1.32
/GPIO13/PWM1: J1.33
/GPIO14/TXD0/CS: J1.8
/GPIO15/RXD0: J1.10
/GPIO16/RTD_IRQ: J1.36, U1.1 (~DRDY)
/GPIO17: J1.11
/GPIO18/PCM.CLK: J1.12
/GPIO19/PCM.FS: J1.35
/GPIO20/ZERO_CROSS: J1.38, R2.2, U2.5
/GPIO21/SSR1: J1.40, J2.3
/GPIO22: J1.15
/GPIO23: J1.16
/GPIO24: J1.18
/GPIO25: J1.22
/GPIO26/SSR2: J1.37, J2.5
/GPIO27: J1.13
/ID_SCL: J1.28
/ID_SDA: J1.27
/RTD+: C3.1, J2.8, JP2.1 (A), U1.10 (RTDIN+)
/RTD-: C3.2, J2.9, JP3.1 (A), U1.11 (RTDIN-)
GND: C1.2, C2.2, J1.6, J1.9, J1.14, J1.20, J1.25, J1.30, J1.34, J1.39, J2.4, J2.6, JP1.3 (B), R7.2, U1.13 (GND), U1.18 (DGND), U1.19 (GND), U2.4
unnamed: R3.2, R4.1
unnamed: R4.2, U2.1
unnamed: R5.2, R6.1
unnamed: R6.2, U2.2
unnamed: R7.1, U2.6
unnamed: R1.1, U1.4 (BIAS), U1.5 (REFIN+)
unnamed: R1.2, U1.6 (REFIN-), U1.7 (ISENSOR)

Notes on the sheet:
Additional pin functions: https://pinout.xyz/

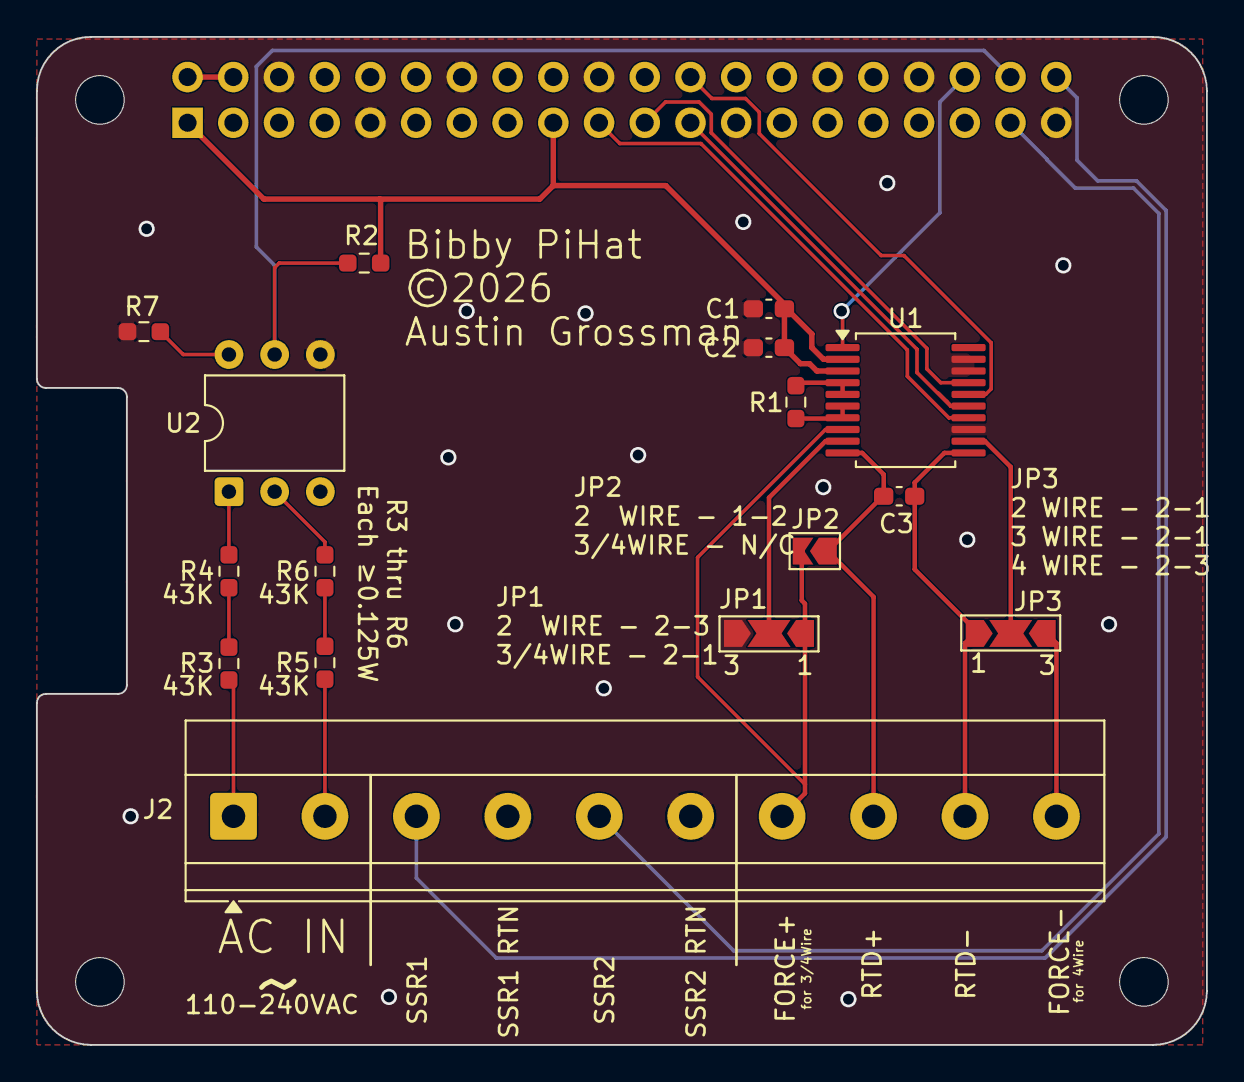
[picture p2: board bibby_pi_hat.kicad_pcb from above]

Board: 2 copper layers, 65.0 x 56.0 mm, 21 parts (1 on the bottom side), 26 nets.

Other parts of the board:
MH1, MH2, MH3, MH4: MountingHole_2.7mm_M2.5

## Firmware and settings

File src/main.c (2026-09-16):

#include <gpiod.h>
#include <pthread.h>
#include <signal.h>
#include <stdio.h>
#include <stdlib.h>
#include <string.h>
#include <sys/mman.h>
#include <time.h>
#include <unistd.h>

#include "config.h"
#include "csv_logger.h"
#include "max31865.h"
#include "sampler_thread.h"
#include "single_instance.h"
#include "ssr_thread.h"
#include "state.h"
#include "ui/ui.h"
#include "web/web.h"

// Pin map (fixed by the HAT; see README).
#define GPIO_CHIP  "/dev/gpiochip4"   // Pi 5
#define GPIO_DRDY  16u                // MAX31865 data-ready, active low
#define GPIO_ZC    20u                // mains zero-cross pulse, rising edge
#define GPIO_SSR1  21u                // element 1 SSR drive
#define GPIO_SSR2  26u                // element 2 SSR drive

static BibbyState g_state;

static void handle_signal(int sig) {
  (void)sig;
  atomic_store(&g_state.running, false);
}

// ── GPIO requests ─────────────────────────────────────────────────────────────
// Each request is created here, before any thread runs; the SSR outputs are
// driven low the instant the request is granted (elements off at startup).
// The kernel releases all lines when the process dies, whatever the cause, and
// the SoC pull-downs then hold the SSR inputs low (elements off on crash).

static struct gpiod_line_request *request_lines(
    struct gpiod_chip *chip, const char *consumer,
    const unsigned *offsets, int count,
    enum gpiod_line_direction direction, enum gpiod_line_edge edge) {
  struct gpiod_line_settings *ls = gpiod_line_settings_new();
  gpiod_line_settings_set_direction(ls, direction);
  if (direction == GPIOD_LINE_DIRECTION_OUTPUT)
    gpiod_line_settings_set_output_value(ls, GPIOD_LINE_VALUE_INACTIVE);
  if (edge != GPIOD_LINE_EDGE_NONE)
    gpiod_line_settings_set_edge_detection(ls, edge);

  struct gpiod_line_config *lc = gpiod_line_config_new();
  gpiod_line_config_add_line_settings(lc, offsets, count, ls);

  struct gpiod_request_config *rc = gpiod_request_config_new();
  gpiod_request_config_set_consumer(rc, consumer);

  struct gpiod_line_request *req = gpiod_chip_request_lines(chip, rc, lc);
  gpiod_request_config_free(rc);
  gpiod_line_config_free(lc);
  gpiod_line_settings_free(ls);
  return req;
}

// Worker threads get explicit modest stacks: the default 8 MB per thread blows
// the RLIMIT_MEMLOCK budget once the process is memory-locked, and these loops
// need a few kilobytes. Returns 0 on success.
static int spawn_thread(pthread_t *tid, void *(*fn)(void *), void *arg,
                        const char *name) {
  pthread_attr_t attr;
  pthread_attr_init(&attr);
  pthread_attr_setstacksize(&attr, 512 * 1024);
  int err = pthread_create(tid, &attr, fn, arg);
  pthread_attr_destroy(&attr);
  if (err != 0) {
    fprintf(stderr, "bibby: cannot start %s thread: %s\n", name, strerror(err));
    atomic_store(&g_state.running, false);
  }
  return err;
}

// ── Headless mode (bench/debug, no display) ───────────────────────────────────

static void headless_loop(BibbyState *st) {
  fprintf(stderr, "bibby: headless mode; ^C to exit\n");
  while (atomic_load(&st->running)) {
    struct timespec ts = { 2, 0 };
    nanosleep(&ts, NULL);
    printf("t=%.1f temp=%.2fC duty=%.2f/%.2f demand=%.0fW "
           "zc=%u wdog=%d fault=0x%02x%s\n",
           bibby_now_s(),
           (double)atomic_load(&st->temp_filt_c),
           (double)atomic_load(&st->duty1), (double)atomic_load(&st->duty2),
           (double)atomic_load(&st->p_demand_w),
           atomic_load(&st->zc_count),
           atomic_load(&st->watchdog_alarm) ? 1 : 0,
           atomic_load(&st->rtd_fault),
           atomic_load(&st->rtd_unresponsive) ? " (RTD unresponsive)" : "");
    fflush(stdout);
  }
}

// ── main ──────────────────────────────────────────────────────────────────────

int main(int argc, char **argv) {
  const char *config_path = NULL;
  bool  headless = false;
  bool  ui_test  = false;
  bool  sim_zc   = false;
  float manual_w = 0.0f;
  for (int i = 1; i < argc; i++) {
    if (!strcmp(argv[i], "--headless")) headless = true;
    else if (!strcmp(argv[i], "--ui-test")) ui_test = true;  // panel bring-up screen
    else if (!strcmp(argv[i], "--sim-zc")) sim_zc = true;    // bench: forces mains.simulate_zc on
    else if (!strcmp(argv[i], "--manual-w") && i + 1 < argc)
      manual_w = (float)atof(argv[++i]);  // bench/step-test: manual watts at start
    else if (!strcmp(argv[i], "-c") && i + 1 < argc) config_path = argv[++i];
    else {
      fprintf(stderr, "usage: bibby [-c bibby.ini] [--headless] [--ui-test] "
                      "[--sim-zc] [--manual-w W]\n");
      return 1;
    }
  }

  // One instance only; the kernel drops the flock on any exit.
  if (single_instance_lock("/tmp/bibby.lock") < 0) {
    fprintf(stderr, "bibby: another instance is already running\n");
    return 1;
  }

  BibbyConfig cfg;
  bool cfg_found = config_load(&cfg, config_path);
  fprintf(stderr, "bibby: config %s (%s), %d Hz mains, %.0f+%.0f W\n",
          config_resolved_path(), cfg_found ? "loaded" : "NOT FOUND, defaults",
          cfg.mains_hz, (double)cfg.element1_watts, (double)cfg.element2_watts);

  state_init(&g_state);
  // Bench zero-cross simulation is a config decision (mains.simulate_zc);
  // --sim-zc forces it on for one run. There is no operator control for it.
  atomic_store(&g_state.simulate_zc, sim_zc || cfg.mains_simulate_zc);
  if (sim_zc || cfg.mains_simulate_zc)
    fprintf(stderr, "bibby: ZERO-CROSS SIMULATION ON (%s) - the mains-loss "
                    "watchdog cannot trip; bench use only\n",
            sim_zc ? "--sim-zc" : "mains.simulate_zc");
  atomic_store(&g_state.manual_power_w, manual_w);  // manual mode is the default

  struct sigaction sa = {0};
  sa.sa_handler = handle_signal;
  sigaction(SIGINT, &sa, NULL);
  sigaction(SIGTERM, &sa, NULL);

  struct gpiod_chip *chip = gpiod_chip_open(GPIO_CHIP);
  if (!chip) {
    perror("bibby: gpiod_chip_open " GPIO_CHIP);
    return 1;
  }

  // SSR outputs first — granted low, before anything else can run.
  const unsigned ssr_offsets[] = { GPIO_SSR1, GPIO_SSR2 };
  struct gpiod_line_request *ssr_req = request_lines(
      chip, "bibby-ssr", ssr_offsets, 2,
      GPIOD_LINE_DIRECTION_OUTPUT, GPIOD_LINE_EDGE_NONE);
  const unsigned zc_offset = GPIO_ZC;
  struct gpiod_line_request *zc_req = request_lines(
      chip, "bibby-zc", &zc_offset, 1,
      GPIOD_LINE_DIRECTION_INPUT, GPIOD_LINE_EDGE_RISING);
  const unsigned drdy_offset = GPIO_DRDY;
  struct gpiod_line_request *drdy_req = request_lines(
      chip, "bibby-drdy", &drdy_offset, 1,
      GPIOD_LINE_DIRECTION_INPUT, GPIOD_LINE_EDGE_FALLING);
  if (!ssr_req || !zc_req || !drdy_req) {
    perror("bibby: gpiod line request");
    return 1;
  }

  // Sensor init can fail (unwired bench, bad SPI): the controller still runs,
  // but only manual mode is reachable and the UI shows the sensor as faulted.
  Max31865 sensor;
  bool sensor_ok = max31865_init(&sensor, "/dev/spidev0.0",
                                 cfg.sensor_ref_resistor_ohms, drdy_req,
                                 GPIO_DRDY, cfg.mains_hz,
                                 cfg.sensor_temp_cal_gain,
                                 cfg.sensor_temp_cal_offset) == 0;
  if (!sensor_ok)
    fprintf(stderr, "bibby: MAX31865 init failed — manual mode only\n");

  CsvLogger logger;
  if (csv_logger_open(&logger, cfg.log_high_rate, cfg.log_low_period_s) == 0)
    fprintf(stderr, "bibby: logging to %s (%s rate)\n", logger.path,
            cfg.log_high_rate ? "high" : "low");

  SsrThreadArgs ssr_args = {
    .st = &g_state, .cfg = &cfg,
    .zc_req = zc_req, .ssr_req = ssr_req,
    .ssr1_gpio = GPIO_SSR1, .ssr2_gpio = GPIO_SSR2,
  };
  SamplerThreadArgs sampler_args = {
    .st = &g_state, .cfg = &cfg,
    .sensor = sensor_ok ? &sensor : NULL,
    .logger = &logger, .drdy_req = drdy_req,
  };
  pthread_t ssr_tid, sampler_tid;
  if (spawn_thread(&ssr_tid, ssr_thread_main, &ssr_args, "ssr") != 0 ||
      spawn_thread(&sampler_tid, sampler_thread_main, &sampler_args, "sampler") != 0)
    return 1;

  // Lock current mappings (text, data, the thread stacks just created) so the
  // RT thread never page-faults. Deliberately not MCL_FUTURE: the default
  // RLIMIT_MEMLOCK is 8 MB, and locking future UI allocations against that
  // budget makes them fail outright — worse than leaving them pageable.
  if (mlockall(MCL_CURRENT) != 0)
    perror("bibby: mlockall (continuing)");

  // Optional LAN web interface. It is off unless [web] is configured with a
  // password, and it never touches the SSRs directly: remote taps are injected
  // into the UI as pointer events, so control still flows through the panel's
  // own widgets and interlocks. A failure to start is non-fatal.
  web_start(&g_state, &cfg, logger.path);

  if (headless) {
    headless_loop(&g_state);
  } else if (ui_run_mode(&g_state, &cfg, ui_test) != 0) {
    fprintf(stderr, "bibby: UI failed to start; falling back to headless\n");
    headless_loop(&g_state);
  }

  atomic_store(&g_state.running, false);
  web_stop();
  pthread_join(sampler_tid, NULL);
  pthread_join(ssr_tid, NULL);   // drives SSRs low on its way out

  csv_logger_close(&logger);
  if (sensor_ok) max31865_close(&sensor);
  gpiod_line_request_release(drdy_req);
  gpiod_line_request_release(zc_req);
  gpiod_line_request_release(ssr_req);
  gpiod_chip_close(chip);
  return 0;
}

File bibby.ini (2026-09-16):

# bibby — brew controller configuration
#
# Key parameters another person or another brew setup would need to change.
# The controller reads this file once at startup. Edit values here; no rebuild
# is required. Every runtime parameter lives in this file — nothing worth
# changing is a constant in the source.
#
# Lookup order: -c <path> argument, then $BIBBY_CONFIG, then bibby.ini next to
# the executable, then bibby.ini in the current directory. A missing file or an
# unrecognized key falls back to the built-in default shown for each key below,
# so the controller always comes up.
#
# Comments start with '#' or ';' and may follow a value on the same line.
# Full key reference: README §7. Calibration procedures: README §9.

[mains]
# AC line frequency. 60 = North America, 50 = most of the rest of the world.
# Sets the zero-cross watchdog timeout (half-period + 0.7 ms guard), the
# control-staleness cutoff (2 x Hz zero crossings, ~2 s), and the MAX31865
# noise-rejection notch.
# default: 60
frequency_hz = 60

# simulate_zc — BENCH MODE. When true the SSR thread treats every zero-cross
# watchdog timeout as a zero crossing, so the sigma-delta modulator, the
# control law, the logging and the UI all run with no AC connected. It is a
# commissioning switch, not an operator control: there is deliberately no
# button for it on the panel, because with it on the mains-loss watchdog can
# never trip. Leave it false on anything wired to a kettle. `--sim-zc` on the
# command line forces it on for a single run without editing this file.
# default: false
simulate_zc = false

[element1]
# SSR1 heating element (GPIO21 / pin 40).
# defaults: watts = 2500, area_cm2 = 150
watts    = 4188    ; rated electrical power, W
area_cm2 = 820     ; wetted surface area, cm^2 (drives the equal-flux split)

[element2]
# SSR2 heating element (GPIO26 / pin 37).
watts    = 4607
area_cm2 = 473

[power]
# Anti-scorch cap on surface power density. When > 0, total demand is capped at
# max_flux_w_cm2 * (area1 + area2); the equal-flux split then keeps both
# elements at that same flux. 0 disables the cap, so the only ceiling is the
# summed element rating (10500 W here).
# default: 0
max_flux_w_cm2 = 0

[pid]
# Temperature-loop gains. The control law works in WATTS: kp is W/degC, and the
# output (feedforward + P + I + D, clamped to [0, max power]) is a power demand
# that the equal-flux split turns into per-element duty. ki and kd are discrete
# per-sample gains, already folded with the sample period by
# tools/identify_plant.py — the sample clock is the MAX31865 conversion rate
# (~50/60 Hz). Zero gains mean auto mode commands no power; tune before use.
# defaults: kp = 0, ki = 0, kd = 0
#
# SIMC-PI gains from the 2026-09-07 heat/cool test, water only (no grain):
#   tools/identify_plant.py logs/2026/09/07/15-41-11.csv --ambient 32.75 \
#       --volume-l 45 --lambda 30
#   m = 53.2 L water-equivalent (45 L actually in the kettle), k_loss = 9.7
#   W/degC, L = 9.5 s (power-on corner), tau_c = 30 s, Ti = 158 s. The first
#   pass used the script's default tau_c = 120 s (kp = 1718, ki = 0.056): the
#   2026-09-07 ramp test showed that to be gentle (a 2 degC step took 4 min to
#   first reach setpoint) and still overshooting (0.26 degC on a 2 degC step,
#   0.73 degC on 10 degC) because the integrator accumulated during the long
#   unsaturated approach. tau_c = 30 s makes P saturate above ~1.9 degC of
#   error and, with i_band_c below, keeps the integrator out of the approach.
#   README §9.5 explains tau_c (--lambda).
#   5000+5500 W nominal elements that put out ~85 % of that (mains below the
#   240 V rating). The controller, the log, and the identification all work in
#   the same nominal watts, so the loop is correctly tuned as-is — the 85 %
#   cancels. Only the displayed watts, the batch-size readout and the flux cap
#   are mislabeled (that is why m reads 53 L for 45 L of water). If [element*]
#   watts are ever corrected by a factor s, scale kp and ki by s and
#   feedforward.process_gain_c by 1/s (or re-identify); changing the ratings
#   alone makes the loop 1/s more aggressive. Validate with a setpoint step
#   (README §9.5) before trusting a batch.
kp = 5632.60
ki = 0.606039
kd = 0.0

# Integral separation. The integrator only accumulates while |setpoint - temp|
# is within this many degC; outside the band it holds its value (no growth,
# no reset). The kettle is an integrating plant, so every degree-second of
# error the integrator soaks up on the way to setpoint has to be paid back as
# overshoot after the crossing — in the 2026-09-07 ramp test that was the
# whole 0.73 degC. The feedforward carries the holding power, so the
# integrator only has model error to trim once the loop is close. Applies in
# both the [pid] and [grain] gain sets. 0 = integrate always (classic PI).
# default: 0
i_band_c = 0.15
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

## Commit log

2026-04-25 First hash out of architecture. Worked on heater-controller and should be mostly done. Not built or tested yet.
2026-04-27 heater-controller working so far. need to test zero cross input. frontend inputs working.
2026-06-17 Still need to test the zero cross input. Temp sensing works and has been tested and passes through a second order moving average filter some restructuring of the display to make it work better. Signa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
2026-06-17 added raspberry pi hat for temp sensor chip, zero crossing detector, and output to SSRs.
    [biab_controller.kicad_sch, bibby_pi_hat.kicad_pcb, bibby_pi_hat.kicad_sch]
2026-06-17 corrections on pi_hat. DRDYn from max chip went to wrong pin and two grounds of max chip weren't connected.
    [biab_controller.kicad_sch, bibby_pi_hat.kicad_pcb, bibby_pi_hat.kicad_sch]
2026-06-17 Timeout for zerocrossing watchdig now a #define. heater-controller and frontend both ensure that only one instance of each can run at a given time. The shared memory between the two processes are nev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
2026-06-19 Safe SSR defaults, frontend auto-launch of controller, PID scaffolding
    heater-controller: zero duty1/duty2 at startup so a restart against the
    persisted shm can't fire the SSRs at a stale duty with no frontend up.
    frontend: launch heater-controller at startup if its shm iteration counter
    isn't advancing; add PID controller scaffolding (runs per temp sample,
    outputs zero for now) and force manual control when an RTD fault makes the
    temperature unreliable.
    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
2026-06-19 INI config system, CSV logging, PID completion, Apache-2.0 license, comprehensive README
    - shared/config.{h,c} + bibby.ini: INI loader for mains frequency, element
    wattage/area, and PID gains; both processes load at startup
    - frontend/csv_logger.{h,cpp}: per-run timestamped CSV with PID terms, temp,
    duty, fault state; flushed each row for crash safety
    - PID: PidTerms struct for logging/tuning; kp/ki/kd wired from config
    - MAX31865: mains filter notch (50/60 Hz) driven from config
    - GUI: kettle illustration and temp history graph improvements
    - LICENSE: MIT → Apache-2.0 (patent grant); pi_hat/LICENSE: CERN-OHL-P-2.0;
    NOTICE: third-party attributions
    - README: comprehensive rewrite cov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
    [bibby.ini, main.c]
2026-06-24 Holding feedforward, conditional-integration anti-windup, decoupled sampling, plant-ID tooling
    PID/control:
    - PidController::update() takes a feedforward arg; output is clamp(ff + p + i + d).
    New [feedforward] INI section (process_gain_c, ambient_c) sized from the step
    test; process_gain_c = 0 disables it (safe default). Feedforward depends on the
    setpoint, not the measurement, so it does not affect loop stability.
    - Replace unconditional integration with conditional integration: hold the
    integrator when the output is railed and the error would push it further in.
    INTEGRAL_MAX is now just a backstop, not the primary anti-windup.
    - Log the feedforward split: new PidTerms::ff and pid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
    [bibby.ini]
2026-09-07 Some monospaced stuff to math type print. Refactored CLAUDE.md and bibby.ini to newer scheme.
2026-09-08 ui bug fix. some updates on plant identification after step response
    [bibby.ini]
2026-09-09 UI graph printing changes (order of lines being printed). identify plant ran on a step response.
2026-09-12 Lots of changes. Added web interface. mc estimation changed to mass estimation in liters now. added integral serpation, which halts the integrator until the temp error is within i_band_c.
    [bibby.ini]
2026-09-13 Mass estimator doesn't need to choose such a long window. Adjusted power of elements to so mass estimation numbers work.
    [bibby.ini]
2026-09-13 Removed delivered power measurments, which were just counting the output of the DSM to the SSRs. This was just a noisy version of the power demanded and useless.
2026-09-16 GUI changes. Zero cross simulation is now only in the config file and it's not a button on the screen. Slider is wider and everything's a bit more comfortable on a small touch screen. Set point, temp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

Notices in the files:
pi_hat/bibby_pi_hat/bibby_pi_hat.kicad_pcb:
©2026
